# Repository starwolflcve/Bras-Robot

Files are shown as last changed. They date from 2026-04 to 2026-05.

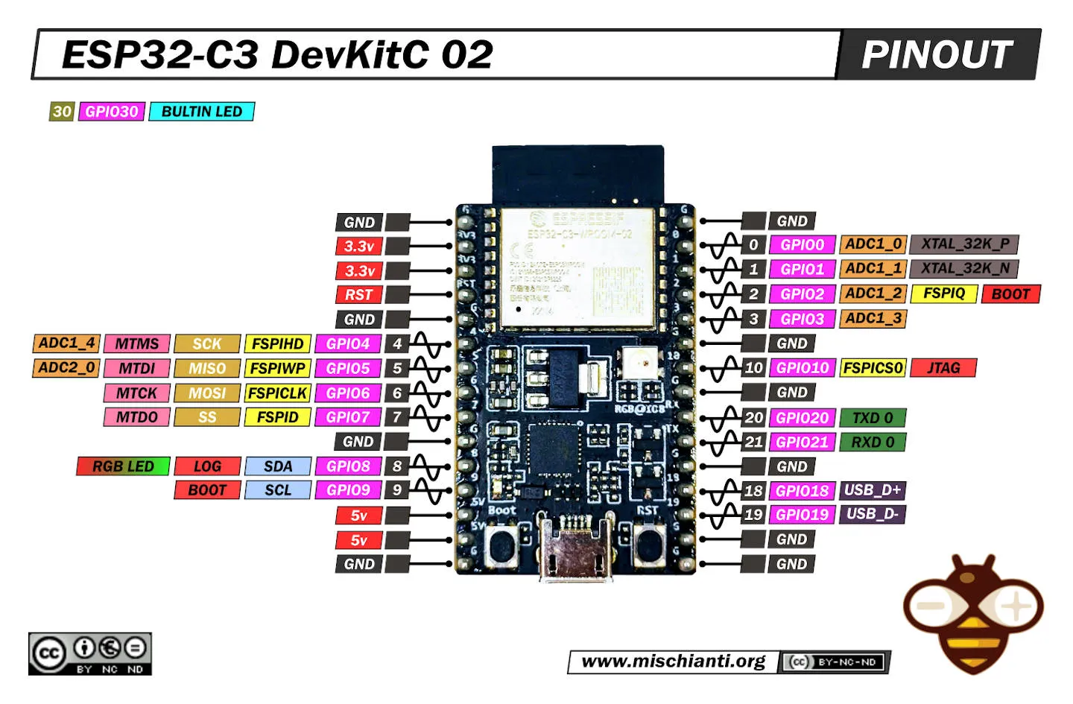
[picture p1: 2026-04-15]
img/pinout-esp32-c3.png

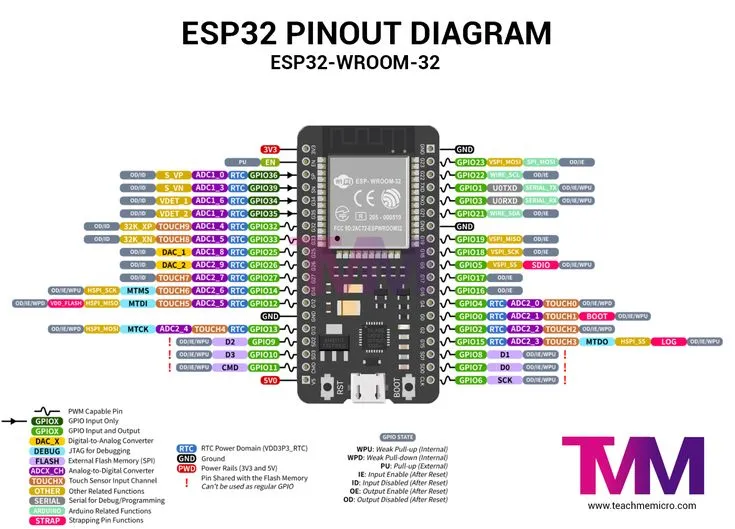
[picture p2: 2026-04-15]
img/pignout-esp32-WROOM-32.png

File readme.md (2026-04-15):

# 🦾 BRAS-ROBOT

> Bras robot articulé à 4 axes, contrôlé sans fil via 2 joysticks — ESP32 + MicroPython + ESP-NOW

---

## 📋 Description

**BRAS-ROBOT** est un bras robotique articulé contrôlé à distance grâce à une manette sans fil maison. Le système repose sur deux ESP32 communicant via le protocole **ESP-NOW** (Wi-Fi sans routeur) :

- **ESP32-C3** → embarqué sur le bras, pilote les 4 servos
- **ESP32-WROOM-32** → dans la manette, lit les 2 joysticks et envoie les données

---

## 🧩 Composants

| Composant | Qté | Rôle |
|---|---|---|
| ESP32-C3 DevKitC-02 | 1 | Cerveau du bras robot (récepteur) |
| ESP32-WROOM-32 | 1 | Cerveau de la manette (émetteur) |
| Servo HS-311 modifié 360° | 1 | Rotation de la base |
| Servo SG90 | 3 | Bras 1, Bras 2, Pince |
| Joystick HW-504 | 2 | Contrôle des 4 axes |
| Breadboard / plaques | 3 | Support de câblage |
| Câbles M-M / M-F | ~20 | Câblage général |
| Câble USB | 1 | Alimentation via PC |

---

## 🔌 Câblage

### Bras Robot (ESP32-C3)

| Servo | Broche ESP32-C3 | Rôle |
|---|---|---|
| HS-311 Base (Signal) | GPIO 3 | Rotation gauche/droite |
| SG90 Bras 1 (Signal) | GPIO 7 | Haut/bas segment 1 |
| SG90 Bras 2 (Signal) | GPIO 8 | Haut/bas segment 2 |
| SG90 Pince (Signal) | GPIO 9 | Ouverture/fermeture |
| Tous les VCC | 5V (VBUS) | Alimentation servos |
| Tous les GND | GND | Masse commune |

### Manette (ESP32-WROOM-32)

| Joystick | Broche | GPIO | Rôle |
|---|---|---|---|
| J1 | VRX | 33 | Rotation base |
| J1 | VRY | 32 | Bras 1 |
| J1 | SW | 25 | Reset base + bras 1 |
| J2 | VRX | 34 | Bras 2 |
| J2 | VRY | 35 | Pince |
| J2 | SW | 26 | Reset bras 2 + pince |
| Les deux | VCC | 3V3 | ⚠️ 3.3V uniquement |
| Les deux | GND | GND | Masse |

> ⚠️ **Attention :** Les joysticks s'alimentent en **3.3V**, pas en 5V.

---

## 🕹️ Contrôles

| Action | Joystick | Résultat |
|---|---|---|
| Axe X ↑↓ | J1 | Rotation base (HS-311 360°) |
| Axe Y ←→ | J1 | Bras 1 (0° → 180°) |
| Axe X ↑↓ | J2 | Bras 2 (0° → 180°) |
| Axe Y ←→ | J2 | Pince (0° → 180°) |
| Bouton SW1 | J1 | Reset base + bras 1 à 0° |
| Bouton SW2 | J2 | Reset bras 2 + pince à 0° |

---

## 🚀 Installation & Lancement

### Prérequis

- [Thonny IDE](https://thonny.org/) pour flasher les ESP32
- MicroPython installé sur les deux ESP32
  - [Firmware ESP32-C3](https://micropython.org/download/ESP32_GENERIC_C3/)
  - [Firmware ESP32-WROOM-32](https://micropython.org/download/ESP32_GENERIC/)

### Étape 1 — Récupérer l'adresse MAC du bras robot

Avant de flasher la manette, il faut connaître l'adresse MAC de l'ESP32-C3 (bras).

Branchez l'ESP32-C3 et exécutez ce script dans le REPL MicroPython :

```python
import network
w = network.WLAN(network.STA_IF)
w.active(True)
print(w.config('mac'))
```

Notez l'adresse MAC affichée (ex : `b'\x58\xcfy\x05]\xd8'`).

### Étape 2 — Flasher la manette

Dans `codemanette_final.py`, remplacez la ligne `peer_mac` par l'adresse MAC récupérée à l'étape 1 :

```python
peer_mac = b'\x58\xcfy\x05]\xd8'  # ← Remplacer par votre adresse MAC
```

Copiez le fichier sur l'ESP32-WROOM-32 en tant que `main.py`.

### Étape 3 — Flasher le bras robot

Copiez le code du bras robot sur l'ESP32-C3 en tant que `main.py`.

### Étape 4 — Démarrage

1. **Allumez d'abord le bras robot** (ESP32-C3) — il attend la calibration
2. **Allumez ensuite la manette** (ESP32-WROOM-32) **sans toucher aux joysticks**
3. La calibration se fait automatiquement (20 lectures du point de repos)
4. Le message `Pret ! En attente des ordres...` s'affiche → c'est parti !

---

## ⚙️ Fonctionnalités techniques

**Anti-tremblement**
- Moyenne sur 10 lectures ADC par cycle
- Zone morte de ±200 autour du point de repos
- Le servo ne bouge que si le déplacement dépasse 2°

**Mémoire de position**
- Quand le joystick est au repos, le servo conserve sa dernière position
- Pas de retour automatique à 0°

**Calibration automatique au démarrage**
- 20 lectures à vide pour détecter le point neutre de chaque axe
- S'adapte aux variations propres à chaque joystick

**Communication sans fil ESP-NOW**
- Latence ~20ms
- Pas besoin de réseau Wi-Fi ni de routeur
- Paquet de 10 octets : 4 valeurs ADC (int16) + 2 boutons (byte)

---

## 🔋 Alimentation

- **Servos** → alimentés en **5V** via le VBUS de l'ESP32-C3 (câble USB)
- **Joysticks** → alimentés en **3.3V** via la broche 3V3 de l'ESP32-WROOM-32
- **ESP32** → alimentés via câble USB (PC ou chargeur 5V)

> 💡 Si les servos manquent de puissance, préférez une alimentation externe 5V dédiée sur la breadboard plutôt que de tout tirer depuis l'USB.

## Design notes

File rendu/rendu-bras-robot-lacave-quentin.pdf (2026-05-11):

# BRAS ROBOT

## Documentation Technique

Projet Robotique Scolaire — 2024/2025

Lucas • Quentin • Tym

■ Type de robot | Bras articulé 4 axes sur plateforme roulante
■ Microcontrôleur | ESP32-C3 DevKitC-02 (bras) + ESP32-WROOM-32 (manette)
■ Langage | MicroPython
■ Communication | ESP-NOW (sans fil, peer-to-peer)
■ Équipe | Lucas, Quentin, Tym
■ Durée | ~10 séances journées complètes
■ Contexte | Projet scolaire — client : professeur encadrant
■ Dépôt Git | github.com/starwolflcve/Bras-Robot

DOCUMENTATION TECHNIQUE — BRAS ROBOT | Lucas • Quentin • Tym
Projet Robotique Scolaire — 2024/2025 | Page 2

# Table des matières

### 1. Introduction du projet

— Objectifs
— Contraintes générales
— Attentes du client

### 2. Organisation de l'équipe

— Rôles
— Répartition
— Planification
— Jalons
— Tâches

### 3. Rapport de suivi des séances

— Avancement séance par séance

### 4. Benchmark / Étude de marché

— Solutions existantes
— Comparatif technologies
— Justification des choix

### 5. Cahier des charges fonctionnel (CDCF)

— Fonctions
— Performances
— Contraintes

### 6. Cahier des charges technique (CDCT)

— Composants
— Architecture matérielle
— Architecture logicielle
— Schémas
— Bilan énergétique

### 7. Prototypes et essais

— Versions du code
— Tests unitaires
— Tests d'ensemble

### 8. Résultats

— Améliorations
— Difficultés rencontrées
— Perspectives

### 9. Codes sources

# 1. Introduction du projet

## 1.1 Objectifs du robot

Le projet consiste à concevoir et réaliser un bras robot articulé à 4 axes, destiné à être monté sur une plateforme roulante mobile. L'ensemble forme un système robotique complet : la plateforme assure les déplacements au sol tandis que le bras permet d'interagir avec l'environnement (saisir, déplacer des objets). Le bras est contrôlé à distance sans fil par une manette équipée de deux joysticks.

- Contrôle de 4 axes indépendants : base (rotation 360°), bras 1, bras 2 et pince
- Communication sans fil entre la manette et le bras via le protocole ESP-NOW
- Intégration sur une plateforme roulante — structure mécanique en pièces imprimées en 3D
- Fonctionnement autonome alimenté sur batterie (AA + convertisseur DC-DC)
- Code MicroPython structuré, versionné sur GitHub (V1 → V4)

## 1.2 Contraintes générales

Contrainte | Détail
Budget | < 30 € — composants bas coût disponibles en stock
Temps | ~10 séances de journées complètes
Compétences | Apprentissage MicroPython, ESP-NOW et PWM en cours de projet
Matériel | ESP32-C3, ESP32-WROOM-32, servos SG90 / HS-311, joysticks HW-504
Alimentation | Batteries AA + convertisseur DC-DC (bras) ; USB PC en développement
Environnement | Usage intérieur, surface plane pour la plateforme roulante
Sécurité | Tensions 3,3 V / 5 V uniquement — pas de haute tension
Structure | Pièces mécaniques imprimées en 3D (PLA)

## 1.3 Attentes du client (professeur encadrant)

- Un bras robot opérationnel contrôlable par la manette sans fil
- Une communication ESP-NOW stable et réactive (latence < 50 ms)
- Une documentation technique structurée couvrant l'ensemble du cycle de développement
- Des codes sources commentés et versionnés sur un dépôt GitHub public
- Une présentation orale avec démonstration en fonctionnement

# 2. Organisation de l'équipe

## 2.1 Membres de l'équipe et rôles

Membre | Rôle principal | Responsabilités
Lucas | Responsable software / chef de projet | Architecture logicielle, code bras (récepteur), GitHub
Quentin | Responsable hardware / électronique | Câblage, schémas Fritzing, choix composants, tests
Tym | Responsable manette / intégration | Code manette (émetteur), protocole ESP-NOW, impression 3D

## 2.2 Répartition des responsabilités

- Lucas : développement et versionning du code (4 versions bras + versions manette), architecture logicielle, gestion du dépôt Git
- Quentin : conception du câblage électronique, pinout des ESP32, sélection servos et joysticks, bilan énergétique, schémas Fritzing
- Tym : implémentation du protocole ESP-NOW, code manette, calibration des joysticks, conception et impression 3D des pièces mécaniques

## 2.3 Planification et jalons

Jalon | Objectif | Statut
J1 — Séances 1-2 | Étude du besoin, choix des composants, benchmark | ■ Réalisé
J2 — Séances 3-4 | Câblage, premiers tests servo, modélisation 3D | ■ Réalisé
J3 — Séances 5-6 | Code bras + manette V1-V2 (filaire) | ■ Réalisé
J4 — Séances 7-8 | Migration ESP-NOW sans fil (V3-V4) | ■ Réalisé
J5 — Séances 9-10 | Intégration, tests finaux, documentation | ■ Réalisé

## 2.4 Répartition des tâches

Tâche | Lucas | Quentin | Tym
Étude de marché / benchmark | ● | ● | ●
Schéma électronique (Fritzing) | | ● | ●
Câblage physique | | ● | ●
Modélisation 3D / impression | | ● | ●
Code bras robot (récepteur) | ●
Code manette (émetteur) | | ● | ●
Protocole ESP-NOW | ● | ● | ●
Tests unitaires servos | ● | ● | ●
Tests d'intégration sans fil | ● | ● | ●
Documentation technique | ● | ● | ●
Gestion GitHub | ●

# 3. Rapport de suivi des séances

■■ Projet réalisé sur ~10 séances de journées complètes. Avancement reconstitué à partir des versions de code, schémas Fritzing et modèles 3D produits.

Séanc e | Tâches réalisées | Livrable
1 | Analyse du besoin, définition des objectifs, répartition des rôles, liste des composants | Équipe formée, objectifs clairs
2 | Benchmark solutions existantes, sélection servos SG90 + HS-311, ESP32 et joysticks HW-504 | Liste composants validée
3 | Câblage bras sur 2 breadboards, pinout ESP32-C3, premiers tests PWM manuel | Servos répondant aux commandes
4 | Code V1 (robotbrasv1.py) : test angle_to_duty(), oscillation 60°-120° sur SG90 | V1 fonctionnelle en local
5 | Câblage manette (ESP32-WROOM-32 + 2 joysticks), lecture ADC, schéma Fritzing — Tests : lecture ADC et réponse servos | Joysticks lus + tests validés
6 | Code V2 : lissage ADC (moy. 10 lectures), zone morte ±150, calibration démarrage — Tests : stabilité servos au repos | Bras stable, vibrations réduites
7 | Migration ESP-NOW : config peer MAC, envoi paquets — Tests : portée et latence ESP-NOW | Liaison sans fil testée
8 | Code V3/V4 : struct.pack, réception temps réel, boutons reset — Tests : contrôle 4 axes sans fil | Contrôle sans fil stable et testé
9 | Modélisation 3D pièces, impression PLA — Tests : tenue mécanique, charges servos, autonomie batterie | Structure mécanique opérationnelle
10 | Rédaction documentation, push GitHub — Tests finaux : démonstration complète du système | Livraison finale

# 4. Benchmark / Étude de marché

## 4.1 Solutions existantes sur le marché

Solution | Prix | Avantages | Inconvénients
Kit bras Arduino (Makeblock…) | 50-150 € | Clé en main, documenté | Peu personnalisable, fermé
Bras ROS / Raspberry Pi | 200-500 € | Puissant, vision, IA | Complexité élevée, hors budget
Bras industriel (UR, Kuka) | > 10 000 € | Précision, robustesse | Hors contexte scolaire
Notre solution ESP32 + MicroPython | < 30 € | Flexible, sans fil, économique | Précision limitée, charge faible

## 4.2 Comparaison des technologies de communication

Technologie | Portée | Latence | Complexité | Retenu ?
Fil (UART/I2C) | ~1 m | Très faible | Simple | ■ Trop contraignant
Bluetooth BLE | ~10 m | Faible | Moyenne | ■ Pairing complexe ESP32-C3
Wi-Fi (MQTT) | > 20 m | Moyenne | Élevée | ■ Nécessite routeur
ESP-NOW | ~200 m | Très faible | Faible | ■ Retenu
RF 433 MHz | ~100 m | Faible | Moyenne | ■ Unidirectionnel

■ ESP-NOW retenu : protocole peer-to-peer Espressif, sans infrastructure Wi-Fi. Latence < 5 ms, portée ~200 m en champ libre, natif sur tous les ESP32.

## 4.3 Comparaison des servomoteurs

Servo | Couple | Rotation | Prix | Rôle
SG90 | 1,8 kg.cm | 0°–180° | ~2 € | Bras 1, Bras 2, Pince
HS-311 mod. | 3 kg.cm | 360° continu | ~5 € | Base (rotation libre)
MG90S | 2,2 kg.cm | 0°–180° | ~4 € | Non retenu (budget)
MG996R | 10 kg.cm | 0°–180° | ~8 € | Non retenu (surdimensionné)

## 4.4 Positionnement et adaptations

- Utilisation de composants bas coût largement documentés (SG90, ESP32)
- Remplacement d'un servo 360° dédié par un HS-311 modifié pour la base
- Choix de MicroPython pour la rapidité de prototypage vs C++ Arduino
- ESP-NOW choisi pour éviter la complexité MQTT ou l'appairage Bluetooth
- Pièces mécaniques imprimées en 3D en PLA pour réduire les coûts

# 5. Cahier des charges fonctionnel (CDCF)

## 5.1 Fonctions du robot

ID | Fonction | Critère de validation
FP1 | Contrôler 4 axes du bras (base, bras1, bras2, pince) | Chaque axe répond indépendamment au joystick
FP2 | Recevoir les commandes sans fil | Latence < 50 ms, portée > 3 m
FP3 | Maintenir la position au repos | Servo garde sa dernière position
FC1 | Émettre les commandes depuis la manette | 2 joysticks + 2 boutons actifs
FC2 | Reset des positions via bouton | SW1 → base+bras1 à 90°/25°, SW2 → bras2+pince à 0°
FC3 | Calibration automatique au démarrage | 20 lectures sans intervention
FC4 | Alimentation autonome (batterie) | Fonctionnement ≥ 2 h en usage normal

## 5.2 Performances attendues

- Réactivité : délai perceptible < 100 ms entre action joystick et mouvement
- Stabilité : pas de vibration des servos au repos (zone morte efficace)
- Précision : résolution angulaire ≈ 2,5° par cycle (MAX_STEP_ANGLE)
- Portée sans fil : minimum 5 m en intérieur

## 5.3 Contraintes

Type | Contrainte
Budget | < 30 € de composants
Taille | Bras compact, doit tenir sur la plateforme roulante
Alimentation | 5 V max, courant total servos ≤ 2 A (crête ~3,5 A)
Matériaux | PLA (impression 3D) pour la structure mécanique
Environnement | Usage intérieur, température ambiante
Sécurité | Tensions faibles, limites angulaires logicielles (0°-180°)
Logiciel | MicroPython uniquement, compatible ESP32-C3 et ESP32-WROOM-32

# 6. Cahier des charges technique (CDCT)

## 6.1 Choix des composants

Composant | Référence | Qté | Rôle
Microcontrôleur bras | ESP32-C3 DevKitC-02 | 1 | Récepteur ESP-NOW, contrôle PWM 4 servos
Microcontrôleur manette | ESP32-WROOM-32 | 1 | Émetteur ESP-NOW, lecture ADC joysticks
Servo base | HS-311 modifié 360° | 1 | Rotation continue base (0-360°)
Servo bras 1 | SG90 | 1 | Articulation segment 1 (0°-180°)
Servo bras 2 | SG90 | 1 | Articulation segment 2 (0°-180°)
Servo pince | SG90 | 1 | Ouverture/fermeture pince (0°-180°)
Joystick | HW-504 | 2 | Contrôle 4 axes + 2 boutons reset
Convertisseur DC-DC | Boost/Buck 5V | 1 | Régulation tension alimentation servos
Breadboard / plaques | Standard | 2 | Support câblage sans soudure
Structure mécanique | Impression 3D PLA | - | Base rotative, bras 1, support servos

## 6.2 Architecture matérielle — Schémas de câblage

Schéma de câblage du bras robot (ESP32-C3 + servos)

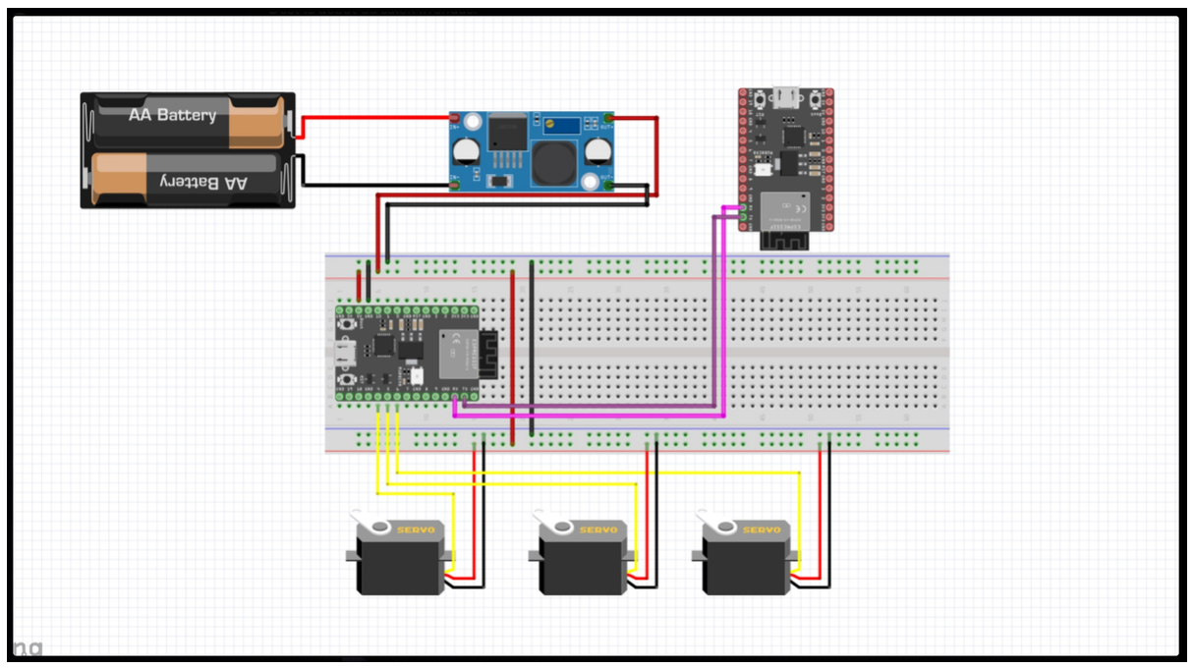
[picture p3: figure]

Figure 1 — Câblage du bras robot : ESP32-C3 DevKitC-02, convertisseur DC-DC, 3 servos SG90 (+ HS-311 base). Alimenté par batteries AA.

Schéma de câblage de la manette (ESP32-WROOM-32 + joysticks)

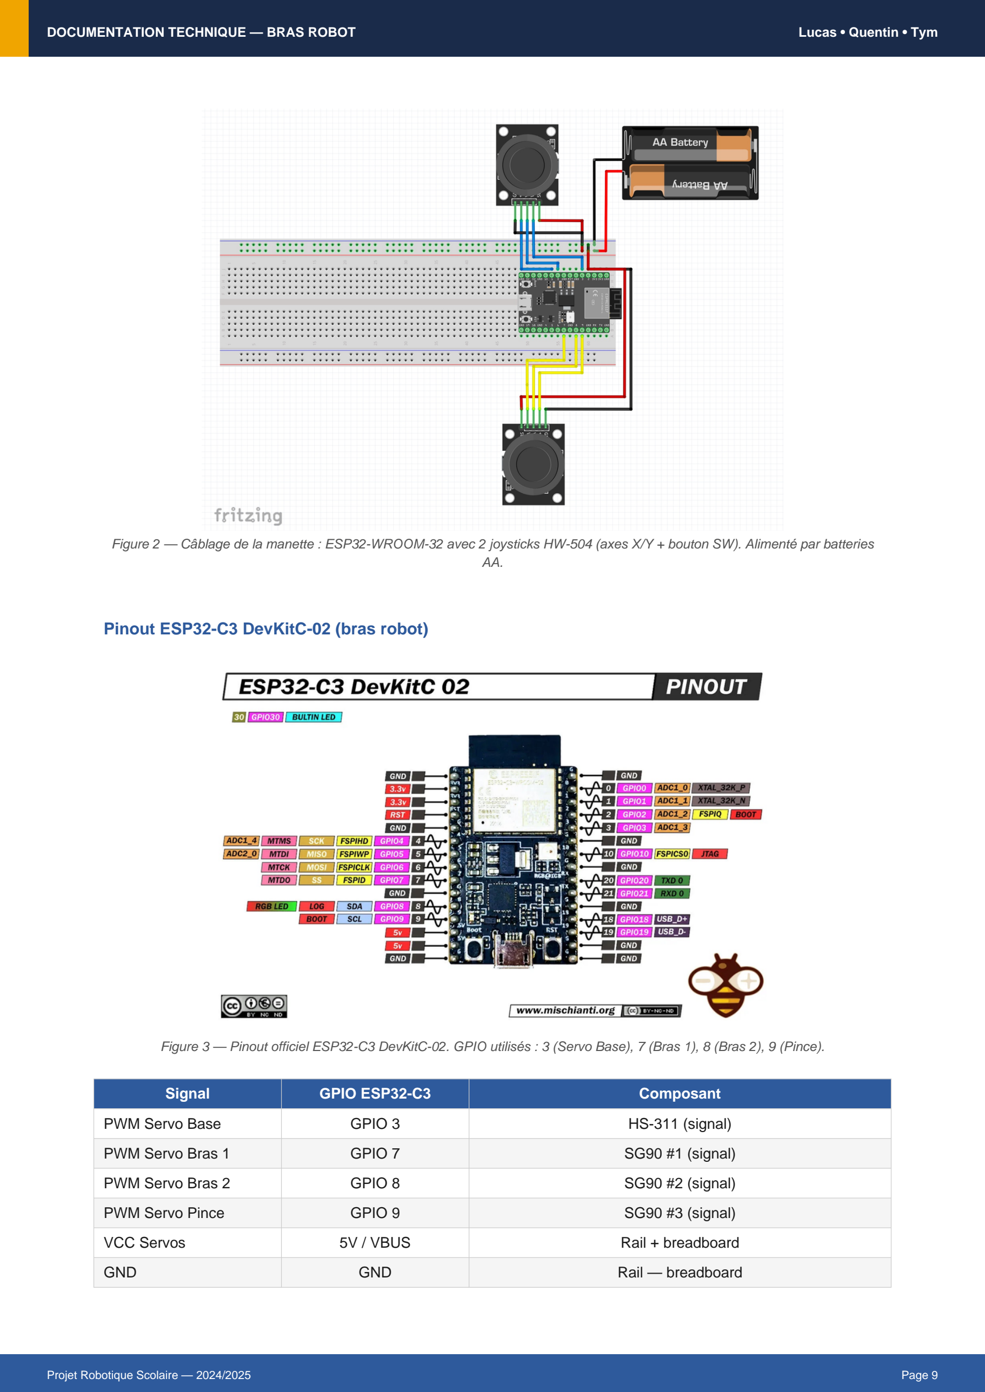
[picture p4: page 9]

Figure 2 — Câblage de la manette : ESP32-WROOM-32 avec 2 joysticks HW-504 (axes X/Y + bouton SW). Alimenté par batteries AA.

Pinout ESP32-C3 DevKitC-02 (bras robot)

Figure 3 — Pinout officiel ESP32-C3 DevKitC-02. GPIO utilisés : 3 (Servo Base), 7 (Bras 1), 8 (Bras 2), 9 (Pince).

Signal | GPIO ESP32-C3 | Composant
PWM Servo Base | GPIO 3 | HS-311 (signal)
PWM Servo Bras 1 | GPIO 7 | SG90 #1 (signal)
PWM Servo Bras 2 | GPIO 8 | SG90 #2 (signal)
PWM Servo Pince | GPIO 9 | SG90 #3 (signal)
VCC Servos | 5V / VBUS | Rail + breadboard
GND | GND | Rail — breadboard

Pinout ESP32-WROOM-32 (manette)

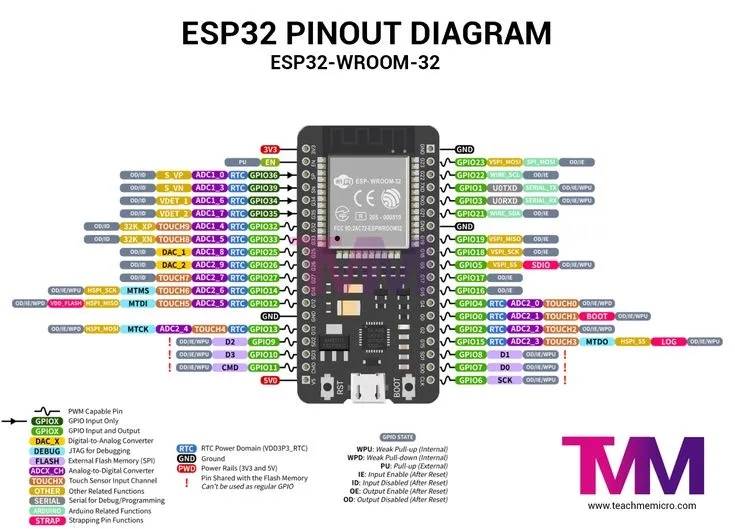
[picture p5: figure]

Figure 4 — Pinout ESP32-WROOM-32. GPIO utilisés : 32,33 (J1), 34,35 (J2), 25,26 (boutons SW).

Signal | GPIO | Composant
ADC J1 VRX | GPIO 33 | Joystick 1 axe X → Base
ADC J1 VRY | GPIO 32 | Joystick 1 axe Y → Bras 1
SW J1 | GPIO 25 | Bouton J1 → Reset Base+Bras1
ADC J2 VRX | GPIO 34 | Joystick 2 axe X → Bras 2
ADC J2 VRY | GPIO 35 | Joystick 2 axe Y → Pince
SW J2 | GPIO 26 | Bouton J2 → Reset Bras2+Pince
VCC Joysticks | 3V3 | Alimentation (pas 5V !)
GND | GND | Masse commune

## 6.3 Structure mécanique — Modélisation 3D

Les pièces mécaniques du bras ont été conçues en CAO et imprimées en PLA :

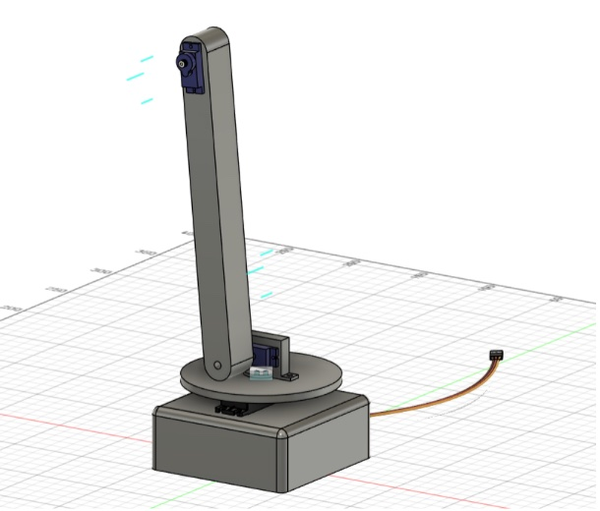
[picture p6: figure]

Figure 5 — Assemblage base rotative + bras 1 (vue CAO)

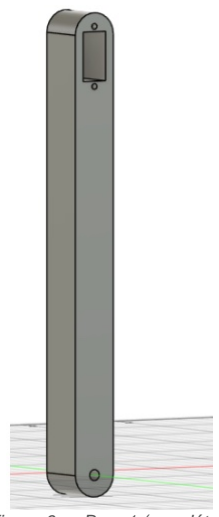
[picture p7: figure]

Figure 6 — Bras 1 (vue détail)

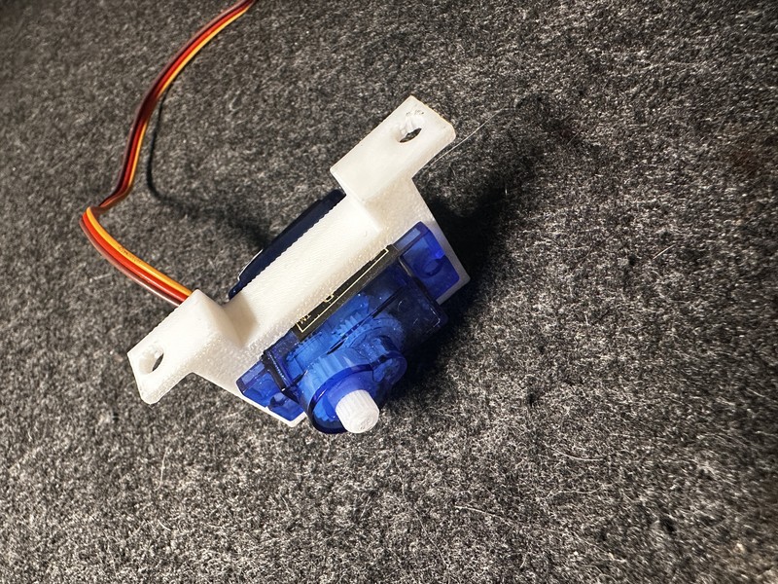
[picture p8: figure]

Figure 7 — Servo SG90 avec support d'articulation imprimé en 3D (PLA blanc)

## 6.4 Architecture logicielle

Le logiciel est divisé en deux programmes MicroPython indépendants :

Côté bras (récepteur — ESP32-C3)

main_bras.py

■

■■■ INITIALISATION

■ ■■■ 4 × PWM (GPIO 3,7,8,9) — freq 50 Hz

■ ■■■ ESP-NOW (mode STA_IF)

■

■■■ calibrer_distance() ← moyenne 20 trames au démarrage

■

■■■ adc_to_step() ← ADC → vitesse angulaire (zone morte)

■■■ set_angle() ← angle → duty cycle 16 bits

■

■■■ BOUCLE PRINCIPALE (toutes les 20 ms)

■■■ e.recv(timeout_ms=20)

■■■ struct.unpack('hhhhbb', msg)

■■■ Mise à jour angles (max 2.5°/cycle)

■■■ Bouton SW1 → reset base + bras1

■■■ Bouton SW2 → reset bras2 + pince

Côté manette (émetteur — ESP32-WROOM-32)

main_manette.py

■

■■■ INITIALISATION

■ ■■■ 4 × ADC (GPIO 32,33,34,35) — ATTN_11DB

■ ■■■ 2 × Pin IN PULL_UP (GPIO 25,26)

■ ■■■ ESP-NOW + add_peer(MAC_bras)

■

■■■ BOUCLE PRINCIPALE (toutes les 20 ms)

■■■ Lecture 4 axes ADC (0-4095)

■■■ Lecture 2 boutons (pull-up inversé)

■■■ struct.pack('hhhhbb', ...)

■■■ e.send(peer_mac, msg)

## 6.5 Bilan énergétique

Composant | Courant typique | Courant crête | Tension
ESP32-C3 (bras) | 80 mA | 240 mA | 3,3 V
ESP32-WROOM-32 | 80 mA | 240 mA | 3,3 V
SG90 × 3 | 450 mA | 2 100 mA | 5 V
HS-311 × 1 | 200 mA | 700 mA | 5 V
Joysticks HW-504 × 2 | 10 mA | — | 3,3 V
TOTAL estimé | ~820 mA | ~3 500 mA | 5 V

■ Alimentation retenue : Batteries AA + convertisseur DC-DC 5V pour le bras. Autonomie estimée ≈ 2 h en usage intensif. USB PC utilisé en phase de développement.

# 7. Prototypes et essais

## 7.1 Versions du code

Version | Fichier | Description
V1 | robotbrasv1.py | Test servo local : duty cycle, oscillation 30°. Validation fonctionnement base.
V2 | brasrobot-V2.py | Ajout joysticks filaires. Lissage ADC (moy. 10 lectures), zone morte, calibration démarrage.
V3 | brasrobot-V3.py | Migration ESP-NOW. Séparation bras/manette en 2 ESP32. Envoi struct.pack toutes les 20 ms.
V4 (finale) | brasrobot-V4.py | adc_to_step() pour vitesse variable, MAX_STEP_ANGLE=2.5°, boutons reset, calibration à distance.

## 7.2 Tests unitaires

Test | Méthode | Résultat
Servo SG90 seul | Script oscillation 60°-120° | ■ Réponse correcte
HS-311 360° | Ajustement STOP_DUTY point mort | ■ Point mort calibré
ADC joystick | Lecture brute Serial, plage 0-4095 | ■ Plage OK avec ATTN_11DB
ESP-NOW pair | Envoi ping simple entre 2 ESP32 | ■ Liaison < 5 ms
struct.pack/unpack | Sérialisation 4×int16 + 2×int8 | ■ Données intègres
Bouton reset | Appui SW1/SW2, vérif retour angles | ■ Reset immédiat

## 7.3 Tests d'ensemble

Test | Résult at | Observation
Contrôle 4 axes simultanément | ■ | Léger délai si 4 axes bougent en même temps
Portée ESP-NOW (même pièce) | ■ | Aucune perte de paquet à < 5 m
Stabilité sans contact joystick | ■ | DEAD_ZONE=200 efficace
Test autonomie batterie | ■ | > 2 h en usage normal

# 8. Résultats

## 8.1 Améliorations apportées au fil des versions

- V1 → V2 : passage d'un test statique à un contrôle dynamique par joystick avec lissage ADC
- V2 → V3 : suppression du câble de commande, migration vers ESP-NOW
- V3 → V4 : remplacement de la conversion ADC→angle fixe par une vitesse variable (adc_to_step) pour un contrôle plus fluide
- Ajout de la calibration à distance (le bras reçoit des trames de la manette au repos)
- Conception et impression 3D des pièces mécaniques pour rigidifier l'assemblage

## 8.2 Difficultés rencontrées et solutions apportées

Problèmes techniques

Problème | Solution
Vibrations servos au repos (bruit ADC) | Zone morte DEAD_ZONE=200 + lissage 10 lectures
HS-311 qui ne s'arrête jamais exactement | Calibration manuelle STOP_DUTY pour point mort
MAC address ESP32 inconnue | Lecture via network.WLAN().config('mac') → hard-coding
ADC2 inutilisable avec Wi-Fi/ESP-NOW | Utilisation exclusive broches ADC1 (GPIO 0-5)
Décalage joystick au repos (≠ 2048) | Calibration automatique 20 lectures au démarrage
Saccades lors grands déplacements | Limitation MAX_STEP_ANGLE=2.5° par cycle

Problèmes organisationnels
- Coordination code bras / manette développés en parallèle → interface commune (struct.pack 'hhhhbb' fixe)
- Gestion des versions → dépôt GitHub avec nommage explicite V1→V4
- Un seul montage physique pour les tests → planning de disponibilité en binôme

## 8.3 Possibilités d'amélioration

- Écran OLED sur la manette pour afficher les angles en temps réel
- Enregistrement et rejeu de séquences de mouvements (mode automatique)
- Servos MG90S ou MG996R pour une meilleure charge utile
- Caméra FPV pour contrôle à distance avec retour vidéo
- Structure rigide imprimée en 3D complète (remplacer les breadboards)
- Capteur de force sur la pince pour éviter d'écraser les objets
- Mode cinématique inverse (IK) pour contrôle cartésien XYZ

# 9. Codes sources

■ Ensemble des codes disponibles sur : github.com/starwolflcve/Bras-Robot

## 9.1 Code final — Bras Robot (récepteur ESP32-C3)

# BRAS ROBOT (RECEPTEUR) - ESP32-C3 - MicroPython

import machine, time, network, espnow, struct

PIN_SERVO_BASE=3; PIN_SERVO_BRAS1=7; PIN_SERVO_BRAS2=8; PIN_SERVO_PINCE=9

FREQ_SERVO=50; MIN_DUTY=1638; MAX_DUTY=8192

ADC_MAX=4095; DEAD_ZONE=200; MAX_STEP_ANGLE=2.5

pwm_base=machine.PWM(machine.Pin(PIN_SERVO_BASE),freq=FREQ_SERVO)

pwm_bras1=machine.PWM(machine.Pin(PIN_SERVO_BRAS1),freq=FREQ_SERVO)

pwm_bras2=machine.PWM(machine.Pin(PIN_SERVO_BRAS2),freq=FREQ_SERVO)

pwm_pince=machine.PWM(machine.Pin(PIN_SERVO_PINCE),freq=FREQ_SERVO)

def set_angle(pwm, angle):

angle=max(0,min(180,angle))

pwm.duty_u16(int(MIN_DUTY+(MAX_DUTY-MIN_DUTY)*angle/180))

def adc_to_step(valeur, repos):

delta=valeur-repos

if abs(delta)<=DEAD_ZONE: return 0.0

if delta>0: return MAX_STEP_ANGLE*(delta-DEAD_ZONE)/(ADC_MAX-repos-DEAD_ZONE)

else: return MAX_STEP_ANGLE*(delta+DEAD_ZONE)/(repos-DEAD_ZONE)

w0=network.WLAN(network.STA_IF); w0.active(True); w0.disconnect()

e=espnow.ESPNow(); e.active(True)

def calibrer_distance():

sx1=sy1=sx2=sy2=0; n=0

while n<20:

host,msg=e.recv(timeout_ms=100)

if msg:

v1x,v1y,v2x,v2y,_,_=struct.unpack('hhhhbb',msg)

sx1+=v1x; sy1+=v1y; sx2+=v2x; sy2+=v2y; n+=1

return sx1//20,sy1//20,sx2//20,sy2//20

def main():

angle_base=90.0; angle_bras1=25.0; angle_bras2=160.0; angle_pince=180.0

[set_angle(p,a) for p,a in zip([pwm_base,pwm_bras1,pwm_bras2,pwm_pince],

[angle_base,angle_bras1,angle_bras2,angle_pince])]

rx1,ry1,rx2,ry2=calibrer_distance()

sw1_last=sw2_last=0

while True:

host,msg=e.recv(timeout_ms=20)

if msg:

v1x,v1y,v2x,v2y,sw1,sw2=struct.unpack('hhhhbb',msg)

for angle,step,pwm,lim in [

(angle_base, adc_to_step(v1x,rx1), pwm_base, (0,180)),

(angle_bras1, adc_to_step(v1y,ry1), pwm_bras1, (0,180)),

(angle_bras2, adc_to_step(v2x,rx2), pwm_bras2, (0,180)),

(angle_pince, adc_to_step(v2y,ry2), pwm_pince, (0,180)),

]:

if step: set_angle(pwm, int(max(lim[0],min(lim[1],angle+step))))

if sw1==1 and sw1_last==0:

angle_base,angle_bras1=90.0,0.0; set_angle(pwm_base,90); set_angle(pwm_bras1,0)

if sw2==1 and sw2_last==0:

angle_bras2,angle_pince=0.0,0.0; set_angle(pwm_bras2,0); set_angle(pwm_pince,0)

sw1_last=sw1; sw2_last=sw2

main()

## 9.2 Code final — Manette (émetteur ESP32-WROOM-32)

# MANETTE SANS FIL - ESP32-WROOM-32 - MicroPython

import network, espnow, machine, struct, time

adc_j1x=machine.ADC(machine.Pin(33)); adc_j1y=machine.ADC(machine.Pin(32))

adc_j2x=machine.ADC(machine.Pin(34)); adc_j2y=machine.ADC(machine.Pin(35))

for adc in [adc_j1x,adc_j1y,adc_j2x,adc_j2y]: adc.atten(machine.ADC.ATTN_11DB)

sw1=machine.Pin(25,machine.Pin.IN,machine.Pin.PULL_UP)

sw2=machine.Pin(26,machine.Pin.IN,machine.Pin.PULL_UP)

w0=network.WLAN(network.STA_IF); w0.active(True); w0.disconnect()

e=espnow.ESPNow(); e.active(True)

peer_mac=b'X\xcfy\x05]\xd8'; e.add_peer(peer_mac)

while True:

msg=struct.pack('hhhhbb',

adc_j1x.read(), adc_j1y.read(),

adc_j2x.read(), adc_j2y.read(),

0 if sw1.value() else 1,

0 if sw2.value() else 1)

try: e.send(peer_mac,msg)

except OSError: pass

time.sleep_ms(20)

## 9.3 Fichiers du dépôt Git

Fichier | Description
robotbrasv1.py | Version 1 — test servo local
brasrobot-V2.py | Version 2 — contrôle joystick filaire
brasrobot-V3.py | Version 3 — migration ESP-NOW
brasrobot-V4.py | Version 4 finale — récepteur bras

codemanette-V1.py | Version finale — émetteur manette

■ https://github.com/starwolflcve/Bras-Robot

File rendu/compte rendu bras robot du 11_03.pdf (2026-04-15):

# Compte Rendu de Séance : Projet Bras Robot

Date : 11/03 Projet : Conception et réalisation d'un bras robotisé

## 1. Objectifs de la séance

L'objectif principal de cette séance était de finaliser la conception 3D, d'avancer sur la fabrication de la structure mécanique du bras robotisé (impression et assemblage de la base), et de tester la caméra initialement prévue pour la détection d'objets.

## 2. Activités réalisées

### 2.1. Test du matériel et changement de système de contrôle

Nous avons commencé par effectuer des tests sur le matériel lié à la vision artificielle :

- Test de la caméra : Nous avons tenté de tester la caméra via Bluetooth pour mettre en place notre système de détection d'objets, mais il manque l’adaptateur pour connecter et tester la caméra. (malgré les effort de tym)
- Changement de cap : Lors des tests, nous avons constaté que la caméra n'était pas complète. Nous avons donc pris la décision d'abandonner le système de détection d'objets par caméra, car il ne nous reste plus assez de séances.
- Nouvelle solution : Le contrôle du bras robotisé se fera finalement par l'intermédiaire d'une manette. Nous avons procédé à la réservation des composants nécessaires pour concevoir cette manette, càd 2 joysticks, 2 boutons-poussoirs, un ESP32, une batterie et une plaque de circuit imprimé (ps : dsl j’ai oublié le nom quand j’ai fait le rendu).

### 2.2. Modélisation et Impression 3D des pièces structurelles

Nous avons travaillé sur la modélisation et l'impression :

- Finalisation des modèles 3D : Nous avons terminé la modélisation 3D de la base et du premier bras du robot.
- Impression 3D : Nous avons ensuite lancé et récupéré l'impression de plusieurs pièces essentielles :
- La base du bras : qui servira de fondation stable à l'ensemble du système.
- Les supports du bras : éléments articulés permettant de lier les différentes sections.

- Le support du servomoteur : pièce cruciale conçue pour accueillir et fixer fermement le moteur qui assurera la rotation de la base ou d'une articulation.

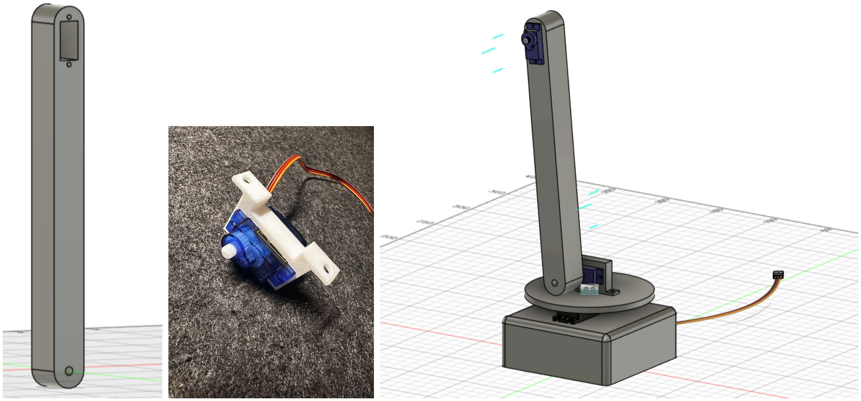
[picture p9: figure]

modelisation by LUCAS

### 2.3. Assemblage mécanique

Une fois les pièces imprimées prêtes et nettoyées, nous sommes passés à la phase de montage :

- Pose des inserts : Nous avons intégré des inserts (inserts thermiques/filetés) dans les pièces en plastique imprimées en 3D avec des inserts et des vis M2, M3 et M4.
- Vissage et montage : Nous avons ensuite assemblé la base, les supports et l'emplacement du servomoteur en les vissant fermement ensemble grâce aux inserts préalablement posés. (ps : dsl Mathis pour le tournevis)

## 3. Difficultés rencontrées

- Modélisation : On a galéré sur Fusion 360 pour faire les pièces.
- Matériel : On a eu du mal à trouver les bons composants qu'il nous fallait et les bonnes vis, écrous et inserts, sachant qu'on a dû tester le matériel. (ps : merci YNOV)

## 4. Bilan

On a super bien avancé malgré l'abandon du système de détection par caméra en raison du matériel incomplet, nous sommes partis sur un contrôle par manette dont le matériel est déjà réservé. Du côté mécanique, l'utilisation des inserts s'est avérée efficace pour garantir un assemblage robuste et la base du bras robot est maintenant montée de manière satisfaisante.

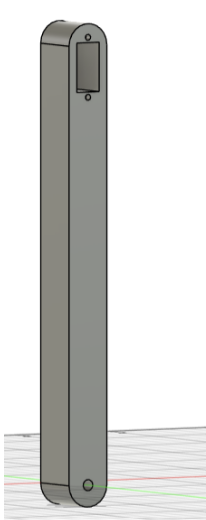
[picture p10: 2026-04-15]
img/bras-1.png

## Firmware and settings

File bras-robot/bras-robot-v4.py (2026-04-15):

# ============================================================
#  BRAS ROBOT (RECEPTEUR) - ESP32-C3 - MicroPython
#  Controle par ESP-NOW (depuis la manette)
# ============================================================

import machine
import time
import network
import espnow
import struct

# ============================================================
# CONFIGURATION PINS (Seulement les servos maintenant !)
# ============================================================
PIN_SERVO_BASE  = 3   # Servo Base
PIN_SERVO_BRAS1 = 7   # SG90 Bras 1
PIN_SERVO_BRAS2 = 8   # SG90 Bras 2
PIN_SERVO_PINCE = 9   # SG90 Pince

# ============================================================
# PARAMATRES PWM & MOUVEMENT
# ============================================================
FREQ_SERVO = 50          # 50 Hz
MIN_DUTY   = 1638        # ~0.5ms -> 0°
MAX_DUTY   = 8192        # ~2.5ms -> 180°

ADC_MAX  = 4095
DEAD_ZONE = 200          # Zone morte pour éviter les tremblements
MAX_STEP_ANGLE = 2.5     # Vitesse de déplacement

# ============================================================
# INITIALISATION SERVOS
# ============================================================
pwm_base  = machine.PWM(machine.Pin(PIN_SERVO_BASE),  freq=FREQ_SERVO)
pwm_bras1 = machine.PWM(machine.Pin(PIN_SERVO_BRAS1), freq=FREQ_SERVO)
pwm_bras2 = machine.PWM(machine.Pin(PIN_SERVO_BRAS2), freq=FREQ_SERVO)
pwm_pince = machine.PWM(machine.Pin(PIN_SERVO_PINCE), freq=FREQ_SERVO)

def set_angle(pwm, angle):
    """Envoie l'angle (0-180) au servo."""
    angle = max(0, min(180, angle))
    duty = int(MIN_DUTY + (MAX_DUTY - MIN_DUTY) * angle / 180)
    pwm.duty_u16(duty)

def adc_to_step(valeur, repos):
    """Calcule de combien on doit augmenter/diminuer l'angle."""
    delta = valeur - repos
    if abs(delta) <= DEAD_ZONE:
        return 0.0
    if delta > 0:
        return MAX_STEP_ANGLE * (delta - DEAD_ZONE) / (ADC_MAX - repos - DEAD_ZONE)
    else:
        return MAX_STEP_ANGLE * (delta + DEAD_ZONE) / (repos - DEAD_ZONE)

# ============================================================
# INITIALISATION ESP-NOW (RECEPTEUR)
# ============================================================
w0 = network.WLAN(network.STA_IF)
w0.active(True)
w0.disconnect()

e = espnow.ESPNow()
e.active(True)

# ============================================================
# CALIBRATION DE DISTANCE
# ============================================================
def calibrer_distance():
    print("En attente de la manette pour la calibration...")
    print("Allumez la manette sans toucher aux joysticks !")
    sx1, sy1, sx2, sy2 = 0, 0, 0, 0
    lectures = 0
    
    while lectures < 20:
        host, msg = e.recv(timeout_ms=100) 
        if msg:
            v1x, v1y, v2x, v2y, sw1, sw2 = struct.unpack('hhhhbb', msg)
            sx1 += v1x; sy1 += v1y; sx2 += v2x; sy2 += v2y
            lectures += 1
            
    print("Calibration a distance OK !")
    return sx1//20, sy1//20, sx2//20, sy2//20

# ============================================================
# BOUCLE PRINCIPALE
# ============================================================
def main():
    print("=== Demarrage Recepteur Bras Robot ===")
    
    # Positions de depart
    angle_base  = 90.0
    angle_bras1 = 0.0
    angle_bras2 = 0.0
    angle_pince = 0.0
    
    set_angle(pwm_base, angle_base)
    set_angle(pwm_bras1, angle_bras1)
    set_angle(pwm_bras2, angle_bras2)
    set_angle(pwm_pince, angle_pince)
    
    rx1, ry1, rx2, ry2 = calibrer_distance()
    
    sw1_last = 0
    sw2_last = 0
    
    print("Pret ! En attente des ordres de la manette...")

    while True:
        host, msg = e.recv(timeout_ms=20)
        
        if msg:
            v1x, v1y, v2x, v2y, sw1, sw2 = struct.unpack('hhhhbb', msg)
            
            s_base  = adc_to_step(v1x, rx1)
            s_bras1 = adc_to_step(v1y, ry1)
            s_bras2 = adc_to_step(v2x, rx2)
            s_pince = adc_to_step(v2y, ry2)
     
            if s_base != 0:
                angle_base = max(0, min(180, angle_base + s_base))
                set_angle(pwm_base, int(angle_base))
                
            if s_bras1 != 0:
                angle_bras1 = max(0, min(180, angle_bras1 + s_bras1))
                set_angle(pwm_bras1, int(angle_bras1))
                
            if s_bras2 != 0:
                angle_bras2 = max(0, min(180, angle_bras2 + s_bras2))
                set_angle(pwm_bras2, int(angle_bras2))
                
            if s_pince != 0:
                angle_pince = max(0, min(180, angle_pince + s_pince))
                set_angle(pwm_pince, int(angle_pince))
     
            # --- Gestion des boutons Reset ---
            if sw1 == 1 and sw1_last == 0:
                angle_base, angle_bras1 = 90.0, 0.0
                set_angle(pwm_base, 90)
                set_angle(pwm_bras1, 0)
                print("Reset J1 via Manette")
            sw1_last = sw1
     
            if sw2 == 1 and sw2_last == 0:
                angle_bras2, angle_pince = 0.0, 0.0
                set_angle(pwm_bras2, 0)
                set_angle(pwm_pince, 0)
                print("Reset J2 via Manette")
            sw2_last = sw2

if __name__ == "__main__":
    main()

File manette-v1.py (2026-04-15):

# ============================================================
#  MANETTE SANS FIL - ESP32-WROOM-32 - MicroPython
#  Emetteur ESP-NOW vers Bras Robot
# ============================================================

import network
import espnow
import machine
import struct
import time

# ============================================================
# CONFIGURATION PINS (ADC1 uniquement)
# ============================================================
# Joystick 1 (Base & Bras 1)
PIN_J1_X = 33
PIN_J1_Y = 32
PIN_J1_SW = 25

# Joystick 2 (Bras 2 & Pince)
PIN_J2_X = 34
PIN_J2_Y = 35
PIN_J2_SW = 26

# ============================================================
# INITIALISATION
# ============================================================
# ADC
adc_j1x = machine.ADC(machine.Pin(PIN_J1_X))
adc_j1y = machine.ADC(machine.Pin(PIN_J1_Y))
adc_j2x = machine.ADC(machine.Pin(PIN_J2_X))
adc_j2y = machine.ADC(machine.Pin(PIN_J2_Y))

# Atténuation 11dB -> Plage 0-3.3V (valeurs de 0 Ã  4095)
adc_j1x.atten(machine.ADC.ATTN_11DB)
adc_j1y.atten(machine.ADC.ATTN_11DB)
adc_j2x.atten(machine.ADC.ATTN_11DB)
adc_j2y.atten(machine.ADC.ATTN_11DB)

# Boutons (pull-up interne)
sw1 = machine.Pin(PIN_J1_SW, machine.Pin.IN, machine.Pin.PULL_UP)
sw2 = machine.Pin(PIN_J2_SW, machine.Pin.IN, machine.Pin.PULL_UP)

# ============================================================
# CONFIGURATION ESP-NOW
# ============================================================
# L'interface Wi-Fi doit etre active en mode Station
w0 = network.WLAN(network.STA_IF)
w0.active(True)
w0.disconnect()

e = espnow.ESPNow()
e.active(True)

peer_mac = b'X\xcfy\x05]\xd8' 
e.add_peer(peer_mac)

# ============================================================
# BOUCLE PRINCIPALE
# ============================================================
def main():
    print("Manette prÃªte ! DÃ©but de la transmission ESP-NOW...")

    while True:
        # Lecture des 4 axes (0 a 4095)
        val_x1 = adc_j1x.read()
        val_y1 = adc_j1y.read()
        val_x2 = adc_j2x.read()
        val_y2 = adc_j2y.read()
        
        # Lecture des boutons (Inversion : 1 = press, 0 = relacher)
        val_sw1 = 0 if sw1.value() else 1
        val_sw2 = 0 if sw2.value() else 1

        msg = struct.pack('hhhhbb', val_x1, val_y1, val_x2, val_y2, val_sw1, val_sw2)

        # Envoi des données au bras robot
        try:
            e.send(peer_mac, msg)
        except OSError as err:
            pass 

        time.sleep_ms(20) 

if __name__ == "__main__":
    main()
